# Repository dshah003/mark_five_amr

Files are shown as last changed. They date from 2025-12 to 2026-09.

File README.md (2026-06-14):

# Mark Five AMR

Jetson Nano based mobile robot with SLAM and autonomous navigation capability, powered by **ROS2 Jazzy + Nav2**.

## Overview

Mark Five AMR is a differential-drive robot platform designed for autonomous navigation and manipulation tasks. The robot uses:
- **Jetson Nano** as the main computer
- **Arduino Mega** for motor control and encoder reading
- **2x BTS7960 (IBT-2)** motor driver modules (one per motor)
- **Intel RealSense D435** depth camera for perception
- **ICM-20948 9-DOF IMU** for sensor fusion (gyro-assisted odometry)
- **Lite Arm i2** 3-DOF robotic arm with PCA9685 PWM driver

## Quick Start

### Prerequisites

#### Install Docker
Follow instructions at https://docs.docker.com/engine/install/ubuntu/

#### Post Installation
```bash
sudo groupadd docker
sudo usermod -aG docker $USER
newgrp docker  # Or logout and log back in
```

### External Dependencies (Build from Source)

The following packages must be cloned into `src/` before building:

```bash
cd ~/mark_five_amr/src

# ICM-20948 IMU driver (requires: pip3 install sparkfun-qwiic-icm20948)
# Note: after cloning, icm20948_node.py must be patched to remove the
# imu.connected check, which fails on Jetson Nano's I2C implementation.
# See the IMU Troubleshooting section below.
git clone https://github.com/norlab-ulaval/ros2_icm20948.git
```

### Docker Setup

```bash
# Build Docker image
cd docker && ./build.sh

# Start container
./start.sh

# Access shell
./bash.sh
```

### Build and Run

```bash
# Inside Docker container
cd ~/mark_five_amr
colcon build
source install/setup.bash

# Launch full robot bringup
ros2 launch mark_five_bot bringup.launch.py

# Or with camera
ros2 launch mark_five_bot bringup.launch.py use_camera:=true
```

## Arduino Setup

The Arduino uses a lightweight serial protocol. A Python ROS2 node (`serial_bridge.py`) handles the translation between serial and ROS2 topics.

### Upload Firmware
```bash
# For BTS7960 motor drivers (current hardware, no library needed)
arduino_ws/Robot_Node_BTS7960/Robot_Node_BTS7960.ino

# For L293DNE H-Bridge (legacy)
arduino_ws/Robot_Node/Robot_Node.ino
```

## Launch Files

### Standalone Mode (single machine)

| Launch File | Description |
|---|---|
| `bringup.launch.py` | Full robot bringup (serial + odometry + IMU/EKF + optional nav) |

### Distributed Mode (Jetson + Workstation)

| Launch File | Description |
|---|---|
| `robot.launch.py` | Jetson-side nodes (serial, odometry, IMU, EKF, camera) |
| `workstation.launch.py` | Workstation-side nodes (SLAM/Nav2, RViz, optional teleop) |

### Component Launch Files

| Launch File | Description |
|---|---|
| `serial.launch.py` | Serial bridge to Arduino |
| `odometry.launch.py` | Encoder-based odometry node |
| `imu.launch.py` | ICM-20948 IMU driver |
| `ekf.launch.py` | EKF sensor fusion (odometry + IMU) |
| `camera.launch.py` | RealSense D435 camera |
| `teleop_keyboard.launch.py` | Keyboard teleoperation |
| `teleop_joy.launch.py` | Joystick teleoperation |
| `navigation.launch.py` | Nav2 navigation stack (SLAM or localization) |
| `slam.launch.py` | Laser SLAM with slam_toolbox |
| `rtabmap_slam.launch.py` | Visual SLAM with RTAB-Map |
| `localization.launch.py` | Localization with pre-built map (AMCL) |
| `mission_manager.launch.py` | Waypoint mission manager |

### Arm Launch Files

| Launch File | Description |
|---|---|
| `arm.launch.py` | Arm controller only (programmatic use) |
| `arm_test.launch.py` | Arm controller + GUI sliders + RViz |
| `display.launch.py` | URDF visualization only (no hardware) |

### Examples

```bash
# Full robot bringup
ros2 launch mark_five_bot bringup.launch.py

# With camera
ros2 launch mark_five_bot bringup.launch.py use_camera:=true

# SLAM mode (build maps)
ros2 launch mark_five_bot bringup.launch.py use_camera:=true use_nav:=true nav_mode:=slam

# Navigation mode (use saved map)
ros2 launch mark_five_bot bringup.launch.py use_camera:=true use_nav:=true nav_mode:=localization map:=/path/to/map.yaml

# Distributed mode - on Jetson
ros2 launch mark_five_bot robot.launch.py
ros2 launch mark_five_bot robot.launch.py camera_mode:=visual_slam

# Distributed mode - on Workstation
ros2 launch mark_five_bot workstation.launch.py slam_mode:=visual teleop:=keyboard
```

## Navigation

### SLAM Mode (Building Maps)
```bash
# Launch robot with SLAM
ros2 launch mark_five_bot bringup.launch.py use_camera:=true use_nav:=true nav_mode:=slam

# Drive around to build the map, then save it
ros2 run nav2_map_server map_saver_cli -f ~/mark_five_amr/src/mark_five_bot/maps/my_map
```

### Localization Mode (Using Saved Maps)
```bash
# Launch with pre-built map
ros2 launch mark_five_bot bringup.launch.py use_camera:=true use_nav:=true nav_mode:=localization map:=/full/path/to/map.yaml

# Open RViz with navigation config
rviz2 -d ~/mark_five_amr/src/mark_five_description/rviz/navigation.rviz

# Set initial pose (2D Pose Estimate tool in RViz)
# Set goal (2D Goal Pose tool in RViz)
```

### Navigation Parameters
Key parameters in `src/mark_five_bot/config/nav2_params.yaml`:
- **Robot radius:** 0.12m
- **Max velocity:** 0.20 m/s linear, 1.0 rad/s angular
- **Controller:** Regulated Pure Pursuit
- **Planner:** NavFn

### Waypoint Mission Manager
```bash
# Launch navigation with mission manager
ros2 launch mark_five_bot navigation.launch.py mode:=localization use_mission_manager:=true

# Load waypoints
ros2 topic pub --once /mission/waypoints geometry_msgs/PoseArray \
  "{header: {frame_id: 'map'}, poses: [\
    {position: {x: 1.0, y: 0.0, z: 0.0}, orientation: {w: 1.0}},\
    {position: {x: 1.0, y: 1.0, z: 0.0}, orientation: {w: 1.0}}\
  ]}"

# Start mission
ros2 service call /mission/start std_srvs/srv/Trigger
```

## IMU and Sensor Fusion

The ICM-20948 9-DOF IMU is fused with wheel odometry using an EKF (`robot_localization` package). Only gyroscope data is used (accelerometer disabled due to vibration noise), providing ~40% reduction in yaw drift during turns.

**Hardware connection (Jetson Nano I2C):**
```
ICM-20948 VIN → Pin 1  (3.3V)
ICM-20948 GND → Pin 6  (GND)
ICM-20948 SDA → Pin 3  (I2C Bus 1 SDA)
ICM-20948 SCL → Pin 5  (I2C Bus 1 SCL)
```

**Verify I2C connection:**
```bash
sudo i2cdetect -y -r 1  # Should show 0x68
```

**Disable IMU if not connected:**
```bash
ros2 launch mark_five_bot robot.launch.py imu:=false
```

### IMU Troubleshooting

**`isDeviceConnected` returns False on Jetson Nano:**
The SparkFun qwiic library's `isDeviceConnected()` uses an I2C probe method that doesn't work on Jetson Nano, even when the device is present and fully functional. The node crashes on `begin()` as a result.

Fix — remove the `connected` check in `src/src/ros2_icm20948/ros2_icm20948/icm20948_node.py`:
```python
# Remove these lines:
if not self.imu.connected:
    self.logger.info("The Qwiic ICM20948 device isn't connected...")

# Keep:
self.imu.begin()
```

Then rebuild:
```bash
colcon build --packages-select ros2_icm20948
```

## Robotic Arm (Lite Arm i2)

3-DOF parallel linkage arm (Thingiverse 480446) with 3x Power HD 1501 MG servos, controlled via PCA9685 PWM driver.

**Hardware connection (shares I2C bus with IMU):**
```
PCA9685 VCC → Pin 1  (3.3V)
PCA9685 GND → Pin 6  (GND)
PCA9685 SDA → Pin 3  (I2C Bus 1 SDA)
PCA9685 SCL → Pin 5  (I2C Bus 1 SCL)
PCA9685 V+  → External 5-6V supply (required for servo power)
```

**Quick start:**
```bash
# On Jetson: run arm controller
ros2 launch mark_five_arm arm_test.launch.py use_rviz:=false use_gui:=false

# Move arm
ros2 topic pub --once /arm/joint_commands sensor_msgs/JointState \
  "{name: ['base', 'shoulder', 'elbow'], position: [0.0, 0.5, -0.3]}"

# Home / relax
ros2 service call /arm/home std_srvs/srv/Trigger
ros2 service call /arm/relax std_srvs/srv/Trigger
```

## Configuration

All parameters are stored in YAML config files:

```
src/mark_five_bot/config/
├── robot_params.yaml          # Physical robot parameters
├── odometry.yaml              # Odometry node settings
├── robot_localization.yaml    # EKF sensor fusion (odometry + IMU)
├── camera.yaml                # RealSense camera settings
├── teleop.yaml                # Teleop (joystick/keyboard) settings
├── nav2_params.yaml           # Nav2 navigation parameters
├── slam_toolbox_params.yaml   # Laser SLAM parameters
├── rtabmap_params.yaml        # Visual SLAM parameters
└── mission_manager.yaml       # Waypoint mission manager settings

src/mark_five_arm/config/
└── arm_params.yaml            # Servo PWM calibration and joint limits
```

## Teleoperation

### Keyboard Control
```bash
# Must run directly (not via launch file)
ros2 run teleop_twist_keyboard teleop_twist_keyboard
```

### Joystick Control
```bash
ros2 launch mark_five_bot teleop_joy.launch.py
```
Hold the enable button (Button 2) while moving the left joystick.

### Manual cmd_vel Publishing
```bash
ros2 topic pub /cmd_vel geometry_msgs/msg/Twist "{linear: {x: 0.3}, angular: {z: 0.0}}" --once
```

## Odometry

The odometry node computes robot position from encoder ticks using differential drive kinematics. When the IMU is connected, the EKF fuses odometry with gyroscope data for improved yaw accuracy.

### Verify Odometry
```bash
ros2 topic echo /odom                              # Raw wheel odometry
ros2 topic echo /odometry/filtered                 # EKF-fused odometry
ros2 run tf2_ros tf2_echo odom base_footprint
ros2 run tf2_tools view_frames
```

## URDF Visualization

```bash
ros2 launch mark_five_description display.launch.py
```

## Robot Specifications

| Parameter | Value |
|---|---|
| Wheel Diameter | 0.055 m |
| Wheel Base | 0.14 m |
| Encoder Ticks per Revolution | 540 |
| Ticks per Meter | 3125 |
| Max Velocity | ~0.37 m/s |

## Project Structure

```
mark_five_amr/
├── src/
│   ├── mark_five_bot/           # Main robot package
│   │   ├── config/              # YAML configuration files
│   │   ├── launch/              # Python launch files
│   │   ├── maps/                # Saved map files
│   │   ├── mark_five_bot/       # Python nodes (serial_bridge, mission_manager)
│   │   └── src/                 # C++ nodes (odometry_node)
│   ├── mark_five_description/   # Robot URDF and RViz configs
│   ├── mark_five_arm/           # Robotic arm package (Lite Arm i2)
│   └── ros2_icm20948/           # IMU driver (cloned from norlab-ulaval)
├── arduino_ws/                  # Arduino firmware
├── docker/                      # Docker configuration
└── docs/                        # Documentation
```

## Documentation

- [Project Roadmap](docs/01-Roadmap.md)
- [System Architecture](docs/02-Architecture.md)
- [Package Reference](docs/05-Package-Reference.md)

## References

- ROS2 Jazzy: https://docs.ros.org/en/jazzy/
- Nav2 Navigation: https://nav2.org/
- slam_toolbox: https://github.com/SteveMacenski/slam_toolbox
- ros2_icm20948: https://github.com/norlab-ulaval/ros2_icm20948
- Lite Arm i2: https://www.thingiverse.com/thing:480446

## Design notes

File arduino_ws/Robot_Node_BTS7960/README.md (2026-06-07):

# Robot_Node_BTS7960

Arduino firmware for Mark Five AMR using **2x BTS7960 (IBT-2)** H-bridge motor driver modules.

**Communication:** Simple serial protocol with ROS2 Python bridge (no library installation needed)

## Why BTS7960?

| Specification | BTS7960 (IBT-2) | Sabertooth 2x12 | L293DNE |
|---|---|---|---|
| Voltage Drop  | <0.5V (MOSFET)  | <0.5V (MOSFET)  | ~3-4V (Darlington) |
| Current (cont)| 43A per channel | 12A per channel | 0.6A per channel |
| Current (peak)| 43A per channel | 25A per channel | 1.2A per channel |
| Control | PWM (0-255) | Serial library  | PWM |
| Modules needed| 2 (one per motor)| 1 | 1 |
| Library | None (built-in) | Dimension Eng.  | None |

## Requirements

### Hardware
- Arduino Mega 2560
- 2x BTS7960 / IBT-2 motor driver modules
- 2x Hall encoder DC geared motors (12V)
- 12V power supply (5A+ recommended)

### Software
- No external library needed — uses standard Arduino `analogWrite()`

## Serial Protocol

```
Arduino TX (publishes):  "t,<left_ticks>,<right_ticks>\n"
Arduino RX (receives):   "v,<linear_x>,<angular_z>\n"
```

The ROS2 `serial_bridge.py` node translates this to ROS2 topics.

## Wiring

### BTS7960 to Arduino Mega

Each BTS7960 module has 6 control pins (RPWM, LPWM, R_EN, L_EN, VCC, GND):

```
+-------------+         +-------------------+         +-------------------+
| Arduino     |         | Left BTS7960      |         | Right BTS7960     |
| Mega 2560   |         |                   |         |                   |
|             |         |  RPWM  (forward)  |         |  RPWM  (forward)  |
|  Pin 5 -----+-------->|  RPWM             |         |                   |
|  Pin 4 -----+-------->|  LPWM             |         |                   |
|  Pin 6 -----+-------->|  R_EN             |         |                   |
|  Pin 7 -----+-------->|  L_EN             |         |                   |
|             |         |                   |         |                   |
|  Pin 8 -----+---------+-------------------+-------->|  RPWM             |
|  Pin 9 -----+---------+-------------------+-------->|  LPWM             |
|  Pin 10 ----+---------+-------------------+-------->|  R_EN             |
|  Pin 11 ----+---------+-------------------+-------->|  L_EN             |
|             |         |                   |         |                   |
|  5V --------+-------->|  VCC              |-------->|  VCC              |
|  GND -------+-------->|  GND              |-------->|  GND (logic)      |
+-------------+         |                   |         |                   |
                        |  B+   B-          |         |  B+   B-          |
  12V Supply ---------->|  B+               |-------->|  B+               |
  GND ----------------->|  B-               |-------->|  B-               |
                        |                   |         |                   |
                        |  M+ (OUT1)        |         |  M+ (OUT1)        |
  Left Motor  <---------|  M+ / M-          | Right   |  M+ / M-  ------->| Right Motor
                        +-------------------+         +-------------------+
```

**Important:** The B+/B- power terminals carry motor current (up to 43A peak). Use adequately rated wire (16AWG minimum).

### Pin Summary

| Arduino Pin | BTS7960 Module | Signal | Description |
|---|---|---|---|
| 5  | Left  | RPWM | Left motor forward PWM |
| 4  | Left  | LPWM | Left motor reverse PWM |
| 6  | Left  | R_EN | Left module enable (right half-bridge) |
| 7  | Left  | L_EN | Left module enable (left half-bridge) |
| 8  | Right | RPWM | Right motor forward PWM |
| 9  | Right | LPWM | Right motor reverse PWM |
| 10 | Right | R_EN | Right module enable (right half-bridge) |
| 11 | Right | L_EN | Right module enable (left half-bridge) |
| 21 (INT0) | — | Left Encoder A  | Interrupt — tick counting |
| 20 | — | Left Encoder B  | Direction sensing |
| 3  (INT1) | — | Right Encoder A | Interrupt — tick counting |
| 2 | — | Right Encoder B | Direction sensing |

## Installation

1. **Open `Robot_Node_BTS7960.ino`** in Arduino IDE — no library installation needed

2. **Wire connections** per the diagram above

3. **Upload firmware** to Arduino Mega:
   - Board: Arduino Mega 2560
   - Port: /dev/ttyACM0

4. **Launch ROS2 robot**:
   ```bash
   ros2 launch mark_five_bot bringup.launch.py
   ```

5. **Test with ROS2**:
   ```bash
   ros2 topic echo /left_ticks
   ros2 topic echo /right_ticks
   ros2 run teleop_twist_keyboard teleop_twist_keyboard
   ```

## Tuning

Initial constants are scaled from the previous Sabertooth values and will need tuning:

| Constant | Value | Description |
|---|---|---|
| `K_P` | 278 | PWM per (m/s) — tune first |
| `b` | 52 | Static PWM offset (deadband compensation) |
| `PWM_MIN` | 60 | Below this → 0 (deadband) |
| `PWM_MAX` | 100 | Safety cap during initial testing (0–255) |
| `PWM_TURN` | 80 | Fixed PWM for turn commands |
| `DRIFT_MULTIPLIER` | 120 | Straight-line correction gain |

**Tuning procedure:**
1. Set `PWM_MAX = 60` and send a `linear_x = 0.1` command — robot should move slowly
2. If it doesn't move, increase `b` or lower `PWM_MIN`
3. Gradually increase `PWM_MAX` to the desired top speed
4. Adjust `DRIFT_MULTIPLIER` if the robot curves during straight-line motion

## Troubleshooting

### Motors don't move
1. Check EN pins: `R_EN` and `L_EN` must be HIGH (set in `setup()`)
2. Check B+/B- have 12V connected to both modules
3. Verify 5V/GND logic connections to VCC/GND on each module
4. Check serial_bridge is running: `ros2 node list | grep serial_bridge`

### Motors spin wrong direction
Swap the motor wire connections (M+ and M−) on the module, **or** swap the RPWM/LPWM pin numbers for that motor in the `#define` block at the top of the sketch.

### Robot drifts to one side
Adjust `DRIFT_MULTIPLIER` (increase to correct more, decrease if oscillating).

### No encoder ticks
- Verify encoder wires on pins 21/20 (left) and 3/2 (right)
- Check encoder power supply (typically 5V from Arduino)

## Robot Parameters

| Parameter | Value | Description |
|---|---|---|
| WHEEL_RADIUS | 0.035 m | Wheel radius (70mm diameter) |
| WHEEL_BASE | 0.36 m | Distance between wheels |
| TICKS_PER_REVOLUTION | 540 | Encoder ticks per revolution |
| TICKS_PER_METER | 2456 | Encoder ticks per meter |

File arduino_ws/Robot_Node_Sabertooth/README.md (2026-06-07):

#include <Sabertooth.h>

# Robot_Node_Sabertooth

Arduino firmware for Mark Five AMR using **Sabertooth 2x12 v1.00** motor driver.

This is an alternative to the original `Robot_Node.ino` which uses the L293DNE H-Bridge.

**Communication:** Simple serial protocol with ROS2 Python bridge (no ros2arduino/micro-ROS needed)

## Why Sabertooth 2x12?

| Specification | Sabertooth 2x12 | L293DNE |
|---|---|---|
| Voltage Drop  | <0.5V (MOSFET)  | ~3-4V (Darlington) |
| Current (cont)| 12A per channel | 0.6A per channel |
| Current (peak)| 25A per channel | 1.2A per channel |
| Protection | Thermal, overcurrent, undervoltage | Thermal only |

## Requirements

### Hardware
- Arduino Mega 2560
- Sabertooth 2x12 motor driver (tested with v1.00)
- 2x Hall encoder DC geared motors (25GA370 or similar, 12V)
- 12V power supply (3A+ recommended)

### Software
- **Sabertooth Arduino Library** by Dimension Engineering
  - Install via: Sketch -> Include Library -> Manage Libraries -> Search "Sabertooth"
  - Or download from: https://www.dimensionengineering.com/info/arduino

**Note:** ros2arduino and micro-ROS are NOT needed. The simple serial protocol is more reliable on Arduino Mega's limited 8KB RAM.

## Serial Protocol

The Arduino uses a lightweight text-based serial protocol:

```
Arduino TX (publishes):  "t,<left_ticks>,<right_ticks>\n"
Arduino RX (receives):   "v,<linear_x>,<angular_z>\n"
```

The ROS2 `serial_bridge.py` node translates this to ROS2 topics.

## DIP Switch Configuration

**Packetized Serial Mode, Address 128:**

```
Switch: 1   2   3   4   5   6
        OFF OFF ON  ON  ON  ON
```

Use the DIP Wizard for other configurations:
http://www.dimensionengineering.com/datasheets/SabertoothDIPWizard/start.htm

## Wiring Diagram

```
+-------------+                     +-----------------+
| Arduino     |                     |  Sabertooth 2x12|
| Mega 2560   |                     |                 |
|             |                     |  S1    S2       |
|  Pin 18 TX1 +-------------------->|  S1             |
|             |                     |                 |
|         GND +-------------------->|  0V             |
+-------------+                     |                 |
                                    |  B+    B-       |
      +12V DC Supply +------------->|  B+             |
      (3A+ recommended)             |                 |
                   GND +----------->|  B-             |
                                    |                 |
                                    |  M1A  M1B       |
      Left Motor <------------------|  M1A  M1B       |
                                    |                 |
                                    |  M2A  M2B       |
      Right Motor <-----------------|  M2A  M2B       |
                                    +-----------------+
```

## Pin Connections

### Arduino Mega to Sabertooth

| Arduino Pin | Sabertooth | Description |
|---|---|---|
| Pin 18 (TX1)| S1 | Serial TX (commands) |
| GND | 0V | Common ground |

### Arduino Mega to Encoders

| Arduino Pin | Encoder | Description |
|---|---|---|
| Pin 21 (INT0) | Left Encoder A  | Interrupt - tick counting |
| Pin 20 | Left Encoder B  | Direction sensing |
| Pin 3 (INT1)  | Right Encoder A | Interrupt - tick counting |
| Pin 2 | Right Encoder B | Direction sensing |

### Motor Connections

| Sabertooth | Motor |
|---|---|
| M1A, M1B | Left Motor terminals |
| M2A, M2B | Right Motor terminals |

**Note:** If motors spin in wrong direction, swap M1A/M1B or M2A/M2B, or swap motor(1)/motor(2) in code.

## ROS2 Topics (via serial_bridge.py)

### Published Topics

| Topic | Type | Description |
|---|---|---|
| `/left_ticks` | std_msgs/Int16 | Left wheel encoder ticks |
| `/right_ticks` | std_msgs/Int16 | Right wheel encoder ticks |

### Subscribed Topics

| Topic | Type | Description |
|---|---|---|
| `/cmd_vel` | geometry_msgs/Twist | Velocity commands |

## Installation

1. **Install Sabertooth library** in Arduino IDE:
   - Sketch -> Include Library -> Manage Libraries
   - Search "Sabertooth" -> Install

2. **Set DIP switches**: `OFF OFF ON ON ON ON`

3. **Wire connections** per the diagram above

4. **Upload firmware** to Arduino Mega:
   - Board: Arduino Mega 2560
   - Port: /dev/ttyACM0

5. **Launch ROS2 robot**:
   ```bash
   ros2 launch mark_five_bot bringup.launch.py
   ```
   This automatically starts the serial_bridge node.

6. **Test with ROS2**:
   ```bash
   # Terminal 1 - Launch robot (already running)

   # Terminal 2 - Monitor encoder ticks
   ros2 topic echo /left_ticks
   ros2 topic echo /right_ticks

   # Terminal 3 - Keyboard teleop
   ros2 run teleop_twist_keyboard teleop_twist_keyboard
   ```

## Troubleshooting

### Motors don't move

1. Check DIP switch settings: `OFF OFF ON ON ON ON`
2. Verify power supply connected to B+/B-
3. Check S1 connected to Arduino Pin 18
4. Ensure common ground between Arduino and Sabertooth
5. Verify Sabertooth library is installed
6. Check serial_bridge node is running: `ros2 node list`

### No topics appearing

1. Check serial_bridge is running:
   ```bash
   ros2 node list | grep serial_bridge
   ```
2. Check Arduino is connected to correct port (`/dev/ttyACM0`)
3. Verify baud rate matches (115200)
4. Test serial directly:
   ```bash
   cat /dev/ttyACM0
   # Should see: t,0,0 (tick messages)
   ```

### Motors spin wrong direction

Swap motor wire connections (M1A/M1B or M2A/M2B), or in the code swap:
```cpp
ST.motor(1, leftWithSign);   // Try swapping 1 and 2
ST.motor(2, rightWithSign);
```

### Robot drifts to one side

Adjust the `DRIFT_MULTIPLIER` constant in the code (default: 120).

## Robot Parameters

| Parameter | Value | Description |
|---|---|---|
| WHEEL_RADIUS | 0.055 m | Wheel radius |
| WHEEL_BASE | 0.14 m | Distance between wheels |
| TICKS_PER_REVOLUTION | 540 | Encoder ticks per wheel revolution |
| TICKS_PER_METER | 3125 | Encoder ticks per meter traveled |

## Power Supply Requirements

| Specification | Recommended |
|---|---|
| Voltage | 12-14V DC |
| Current | 3A minimum, 5A preferred |
| Type | Regulated DC supply or 3S LiPo battery |

**Important:** Do not use a 5V->12V boost converter. The Sabertooth requires direct 12V with adequate current capacity.

## Files

- `Robot_Node_Sabertooth.ino` - Main Arduino firmware
- `README.md` - This file

## Test Code

For standalone motor testing (without ROS2), see:
- `arduino_ws/test_sabertooth/test_sabertooth.ino` - Full test sequence
- `arduino_ws/test_sabertooth_minimal/test_sabertooth_minimal.ino` - Minimal test

## Migration from ROS1

The ROS2 version uses a **simple serial protocol** instead of rosserial. Key changes:
- No ROS libraries needed on Arduino (just Sabertooth library)
- ROS2 `serial_bridge.py` node handles translation
- Much lower memory footprint on Arduino
- More reliable than ros2arduino/micro-ROS on Arduino Mega

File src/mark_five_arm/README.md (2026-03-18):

 # Mark Five Arm - ROS2 Robotic Arm Controller

ROS2 package for controlling a hobby servo-based robotic arm using the PCA9685 PWM driver board.

## Overview

This package provides a ROS2 node that interfaces with a PCA9685 16-channel PWM driver to control hobby servos for a robotic arm. It converts joint position commands (in radians) to PWM signals and provides services for homing and relaxing the arm.

### Features

- **ROS2 Jazzy** compatible
- **PCA9685 I2C interface** for controlling up to 16 servos
- **Configurable joint parameters** via YAML files (angle ranges, PWM limits, home positions)
- **ROS2 services** for homing and relaxing the arm
- **Joint state publishing** for monitoring current positions
- **Simulation mode** for testing without hardware
- **GUI testing tool** with joint sliders for manual control

## Supported Arm Designs

This package is configured for the **Lite Arm i2** (Thingiverse thing:480446) - a 4-DOF robotic arm modeled after the uFactory uArm.

**Lite Arm i2 Specifications (Official):**
- **3-4 servos:** 3x Power HD 1501 MG (base, shoulder, elbow) + optional gripper servo
- **4 DOF:** Base rotation (Z-axis), Shoulder (Y-axis), Elbow (Y-axis), Gripper
- **Design:** Inspired by ABB IRB-660 industrial robot
- **3D Printed:** All structural parts are 3D printable
- **STL Files:** Available on [Thingiverse thing:480446](https://www.thingiverse.com/thing:480446)
- **Dimensions (from STL analysis):**
  - Upper arm: 230mm (20_21B.stl)
  - Forearm: 180mm (15C.stl)
  - Base bearing: 35mm ID × 47mm OD × 7mm (6807 2RS)
- **PWM Range (calibrated):**
  - Base: 690-2600μs (center: 1645μs)
  - Shoulder: 900-2000μs (center: 1450μs)
  - Elbow: 900-2350μs (center: 1625μs)

The URDF (`urdf/lite_arm_i2.urdf.xacro`) has been updated with dimensions extracted from the official STL files.

**Arm Configuration (3-DOF, parallel linkage):**
```
       End Effector (passive)
            │
            │ (no servo - parallel linkage keeps it level)
            ▼
      ┌─────────────┐
      │  Forearm    │ ← 180mm (15C.stl)
      │ (2 parallel │
      │   links)    │
      └─────┬───────┘
            │ (revolute, Y-axis)
         Elbow (CH2)
            │
      ┌─────────────┐
      │ Upper Arm   │ ← 230mm (20_21B.stl)
      │ (2 parallel │
      │   links)    │
      └─────┬───────┘
            │ (revolute, Y-axis)
       Shoulder (CH1)
            │
      Rotating Base
            │
            │ (revolute, Z-axis)
        Base (CH0)
            │
         ═════════
        Fixed Base
```

**Note:** The parallel linkage mechanism keeps the end effector/tool at a consistent orientation as the arm moves (similar to ABB IRB-660). The URDF simplifies this to a serial chain for basic visualization. For accurate inverse kinematics, the parallel linkage geometry would need to be modeled.

**Optional Gripper:** Add a gripper servo to channel 3 if needed (see `config/arm_params.yaml`).

## Hardware Requirements

### Components

| Component | Specification | Purpose |
|---|---|---|
| **PCA9685** | 16-channel 12-bit PWM driver | Servo control via I2C |
| **Hobby Servos** | 4.8-6V, standard PWM (1000-2000μs) | Arm joints |
| **Power Supply** | 5-6V, ≥2A per servo | Servo power |
| **Jetson Nano** | Or similar SBC with I2C | Robot computer |
| **Jumper Wires** | Female-to-female | I2C connections |

### Official Servos (Lite Arm i2)

As specified in the official parts list:
- **3x Power HD 1501 MG servos** (base, shoulder, forearm) - $15.95 each
  - Operating voltage: 4.8-6V
  - PWM range: Varies per joint (see calibrated values above)
  - Torque: ~15kg-cm @ 6V
- **Optional gripper servo:** Any standard servo (SG90 or similar)

### uArm Swift Pro (Example Configuration)

If using a **uArm Swift Pro** or similar commercial arm:
- Base: 180° rotation
- Shoulder: 0-90° range
- Elbow: 0-90° range
- Wrist: 180° rotation
- Gripper: Open/close (0-60°)

You'll need to replace the original controller with the PCA9685 and rewire the servos.

## Circuit Diagram

### PCA9685 to Jetson Nano I2C Connection

```
┌─────────────────┐              ┌─────────────────────┐
│  Jetson Nano    │              │     PCA9685         │
│  (GPIO Header)  │              │   PWM Driver        │
├─────────────────┤              ├─────────────────────┤
│                 │              │                     │
│  Pin 1 (3.3V) ──┼─────────────▶│ VCC                 │
│  Pin 3 (SDA)  ──┼─────────────▶│ SDA  [CH0]  [CH8]   │
│  Pin 5 (SCL)  ──┼─────────────▶│ SCL  [CH1]  [CH9]   │
│  Pin 6 (GND)  ──┼─────────────▶│ GND  [CH2]  [CH10]  │
│                 │              │      [CH3]  [CH11]  │
│                 │              │      [CH4]  [CH12]  │
│                 │              │      [CH5]  [CH13]  │
│                 │              │      [CH6]  [CH14]  │
│                 │              │      [CH7]  [CH15]  │
│                 │              │                     │
│                 │              │  V+  ───────────┐   │
│                 │              │  GND ─────────┐ │   │
└─────────────────┘              └───────────────┼─┼───┘
                                                 │ │
                                                 │ │
                                   ┌─────────────┘ │
                                   │  ┌────────────┘
                                   ▼  ▼
                               ┌──────────────┐
                               │ Power Supply │
                               │   5-6V DC    │
                               │   ≥2A/servo  │
                               └──────────────┘
```

### Servo Connections

Each servo connects to a PCA9685 channel:

```
Servo Wire Colors (Standard):
  - Red/Orange: Power (V+) ──▶ PCA9685 V+ terminal
  - Brown/Black: Ground (GND) ──▶ PCA9685 GND terminal
  - Yellow/White: Signal (PWM) ──▶ PCA9685 channel pin

Example 6-DOF Arm:
  CH0: Base rotation servo
  CH1: Shoulder servo
  CH2: Elbow servo
  CH3: Wrist pitch servo
  CH4: Wrist roll servo
  CH5: Gripper servo
```

### Important Wiring Notes

1. **DO NOT power servos from Jetson's 5V pin** - insufficient current (≥2A per servo needed)
2. **Use separate 5-6V power supply** for servo power (V+/GND terminals on PCA9685)
3. **Common ground** - Connect Jetson GND, PCA9685 GND, and power supply GND together
4. **I2C address** - Default PCA9685 address is 0x40 (verify with `i2cdetect`)
5. **I2C bus sharing** - PCA9685 shares I2C bus 1 with IMU (if installed)

## Software Setup

### 1. Build the Package

```bash
# Navigate to workspace
cd ~/mark_five_amr

# Rebuild Docker image with PCA9685 dependencies
cd docker
./build.sh

# Start container
./start.sh
./bash.sh

# Inside container, build the workspace
cd ~/mark_five_amr
colcon build --packages-select mark_five_arm
source install/setup.bash
```

### 2. Verify I2C Connection

Before running the node, verify the PCA9685 is detected:

```bash
# On Jetson host (not Docker)
sudo apt install i2c-tools
sudo i2cdetect -y -r 1

# Expected output:
#      0  1  2  3  4  5  6  7  8  9  a  b  c  d  e  f
# 00:          -- -- -- -- -- -- -- -- -- -- -- -- --
# ...
# 40: 40 -- -- -- -- -- -- -- -- -- -- -- -- -- -- --  ← PCA9685
# ...
# 60: -- -- -- -- -- -- -- -- 68 -- -- -- -- -- -- --  ← IMU (if present)
```

If not detected:
- Check wiring (SDA, SCL, VCC, GND)
- Verify PCA9685 power LED is on
- Check I2C address jumpers on PCA9685 board (default 0x40)

### 3. Configure Servo Parameters

Edit `config/arm_params.yaml` to match your arm:

```yaml
# For each joint, configure:
base:
  channel: 0           # PCA9685 channel (0-15)
  min_angle: -1.5708   # Minimum angle in radians
  max_angle: 1.5708    # Maximum angle in radians
  min_pwm: 1000        # PWM value at min_angle (0-4095)
  max_pwm: 2000        # PWM value at max_angle (0-4095)
  home_angle: 0.0      # Home position in radians
  inverted: false      # Reverse direction if true
```

## Measuring and Updating URDF Dimensions

The included URDF has estimated dimensions. For accurate visualization and future kinematics, measure your printed arm and update the URDF.

### What to Measure

Open `urdf/lite_arm_i2.urdf.xacro` and update these properties at the top:

```xml
<!-- Measure these on your printed arm! -->
<xacro:property name="base_height" value="0.050" />      <!-- Base cylinder height -->
<xacro:property name="base_radius" value="0.045" />      <!-- Base cylinder radius -->

<xacro:property name="upper_arm_length" value="0.148" /> <!-- Shoulder to elbow distance -->
<xacro:property name="forearm_length" value="0.160" />   <!-- Elbow to wrist distance -->
<xacro:property name="gripper_length" value="0.080" />   <!-- Gripper reach -->
```

### How to Measure

1. **Base dimensions:**
   - Measure height and radius of the rotating base platform

2. **Upper arm (shoulder to elbow):**
   - Measure center-to-center distance between shoulder servo axis and elbow servo axis
   - This is the most critical dimension for kinematics

3. **Forearm (elbow to wrist/gripper):**
   - Measure center-to-center distance from elbow servo axis to gripper attachment point

4. **Gripper:**
   - Measure from gripper base to tip of fingers when closed

### Verify URDF in RViz

After updating dimensions:

```bash
ros2 launch mark_five_arm display.launch.py
```

Use the joint sliders to move the arm and verify:
- Links are the correct length
- Joints rotate around correct axes
- No unexpected offsets or rotations

## Hardware Assembly

### Parts List

The official Lite Arm i2 parts list is included in `stl/LAi2Partslist.pdf`. Key components:

**Electronics:**
- 3x Power HD 1501 MG servos ($15.95 each)
- 3x 25T servo horns (3mm threaded)
- PCA9685 PWM driver (not in original - added for ROS2 control)

**Mechanical:**
- 24x MF84zz 4x8x3mm flanged ball bearings ($15 for 24)
- 1x 6807 2RS bearing (35mm ID × 47mm OD) for base rotation ($9.47)
- Various 6-32 and 8-32 bolts and nuts (see PDF for full list)

**3D Printed Parts:**
- 30 STL files included in `stl/` directory
- Print all parts in PLA or PETG
- See assembly instructions in `stl/LAi2_Instructions.zip`

### Assembly Notes

1. Follow the official assembly instructions in `LAi2_Instructions.zip`
2. The original design uses direct Arduino control - we're replacing that with PCA9685 for ROS2 integration
3. Wire servos to PCA9685 channels 0-2 (base, shoulder, elbow)
4. Gripper servo (if used) goes to channel 3

## Calibration

### Official PWM Values (Power HD 1501 MG)

The Lite Arm i2 uses **Power HD 1501 MG** servos with these specs (from official Arduino code):

| Position | PWM Value |
|---|---|
| Full left/min | 1000μs |
| **Center** | **1500μs** |
| Full right/max | 2000μs |

These values are **already configured** in `config/arm_params.yaml`. For most builds, no calibration is needed!

### Quick Test (Verify Default Values Work)

```bash
# Terminal 1: Run arm controller
ros2 launch mark_five_arm arm.launch.py

# Terminal 2: Send all servos to center (1500μs)
ros2 topic pub --once /arm/joint_commands sensor_msgs/JointState \
  "{name: ['base', 'shoulder', 'elbow'], position: [0.0, 0.0, 0.0]}"
```

All three servos should move to their center positions. If this works, the default calibration is correct!

### When Calibration IS Needed

Only calibrate if:
1. **Servo moves wrong direction** → Set `inverted: true` for that joint
2. **Center position is off** → Adjust PWM values slightly
3. **Using different servos** → Find their PWM range

### Calibration Process (If Needed)

**Step 1: Check servo direction**
```bash
# Command positive angle for base
ros2 topic pub --once /arm/joint_commands sensor_msgs/JointState \
  "{name: ['base'], position: [0.5]}"
```
- If base rotates counter-clockwise (looking from above): correct
- If base rotates clockwise: set `base.inverted: true` in config

Repeat for shoulder and elbow.

**Step 2: Verify home position**

The arm should be in a safe "home" pose when all joints are at 0.0:
```bash
ros2 service call /arm/home std_srvs/srv/Trigger
```

If the home position causes collisions or looks wrong, adjust `home_angle` for each joint in the config.

**Step 3: Test full range with GUI**
```bash
ros2 launch mark_five_arm arm_test.launch.py
```

Use the sliders to move each joint through its full range. Verify:
- Smooth motion (no jitter)
- No mechanical binding at limits
- Physical arm matches RViz visualization

### Fine-Tuning PWM (Rare)

If servos don't reach full range or overshoot:

```yaml
# In config/arm_params.yaml
base:
  min_pwm: 1000   # Decrease if servo doesn't reach min position
  max_pwm: 2000   # Increase if servo doesn't reach max position
```

The Power HD 1501 MG servos support extended PWM ranges beyond the nominal 1000-2000μs. Calibrated ranges: base (690-2600μs), shoulder (900-2000μs), elbow (900-2350μs).

### Lite Arm i2 Default Calibration

```yaml
# These values should work out-of-the-box for Lite Arm i2
base:
  channel: 0
  min_angle: -1.5708   # -90°
  max_angle: 1.5708    # +90°
  min_pwm: 1000        # Official spec
  max_pwm: 2000        # Official spec
  home_angle: 0.0      # Center
  inverted: false      # Change if needed
```

## Usage

### 1. Visualize URDF Only (No Hardware)

Visualize the arm model in RViz without connecting to hardware:

```bash
ros2 launch mark_five_arm display.launch.py
```

This launches:
- `robot_state_publisher` - publishes URDF transforms
- `joint_state_publisher_gui` - GUI sliders for joint control
- `rviz2` - visualization

Use this to verify your URDF dimensions before connecting servos.

### 2. Test with Hardware (PCA9685 + Servos)

Test actual servo control with GUI and visualization:

```bash
# Full test with RViz
ros2 launch mark_five_arm arm_test.launch.py

# Or without RViz (faster)
ros2 launch mark_five_arm arm_test.launch.py use_rviz:=false
```

This launches:
- `robot_state_publisher` - publishes URDF transforms
- `arm_controller` - controls PCA9685 hardware
- `joint_state_publisher_gui` - GUI sliders send commands to hardware
- `rviz2` - visualization (optional)

Move the sliders and watch both the physical arm and RViz model move together.

### 2b. Distributed Mode (Jetson + Workstation)

When running on a headless Jetson Nano, run the controller on Jetson and GUI/RViz on your workstation:

**On Jetson (headless):**
```bash
ros2 launch mark_five_arm arm_test.launch.py use_rviz:=false use_gui:=false
```

**On Workstation:**
```bash
# RViz only (view arm state)
ros2 launch mark_five_arm display.launch.py use_gui:=false use_rsp:=false

# GUI control (move arm with sliders)
ros2 run joint_state_publisher_gui joint_state_publisher_gui \
  --ros-args -r /joint_states:=/arm/joint_commands
```

Note: `use_rsp:=false` prevents duplicate `robot_state_publisher` since Jetson is already running it.

### 3. Programmatic Control (No GUI)

Control the arm via ROS2 topics:

```bash
# Terminal 1: Start arm controller only
ros2 launch mark_five_arm arm.launch.py

# Terminal 2: Command joints via topic (positions in radians)
ros2 topic pub --once /arm/joint_commands sensor_msgs/JointState \
  "{name: ['base', 'shoulder', 'elbow'], position: [0.5, 0.3, -0.5]}"
```

### Services

```bash
# Move to home position
ros2 service call /arm/home std_srvs/srv/Trigger

# Relax all servos (disable PWM)
ros2 service call /arm/relax std_srvs/srv/Trigger
```

### Monitor Joint States

```bash
# View current joint positions
ros2 topic echo /arm/joint_states

# Check publishing rate
ros2 topic hz /arm/joint_states
```

## ROS2 Interface

### Subscribed Topics

| Topic | Type | Description |
|---|---|---|
| `/arm/joint_commands` | `sensor_msgs/JointState` | Target joint positions (radians) |

### Published Topics

| Topic | Type | Rate | Description |
|---|---|---|---|
| `/arm/joint_states` | `sensor_msgs/JointState` | 10 Hz | Current commanded positions |

### Services

| Service | Type | Description |
|---|---|---|
| `/arm/home` | `std_srvs/Trigger` | Move arm to home position |
| `/arm/relax` | `std_srvs/Trigger` | Disable all servos (zero PWM) |

### Parameters

| Parameter | Type | Default | Description |
|---|---|---|---|
| `i2c_address` | int | 0x40 | PCA9685 I2C address |
| `pwm_frequency` | int | 50 | PWM frequency (Hz) |
| `num_joints` | int | 6 | Number of servo joints |
| `joint_names` | list | ['base', ...] | Joint name list |
| `publish_rate` | float | 10.0 | Joint state publish rate (Hz) |

Per-joint parameters (replace `<joint_name>`):
- `<joint_name>.channel` (int): PCA9685 channel (0-15)
- `<joint_name>.min_angle` (float): Minimum angle (radians)
- `<joint_name>.max_angle` (float): Maximum angle (radians)
- `<joint_name>.min_pwm` (int): PWM at min_angle (0-4095)
- `<joint_name>.max_pwm` (int): PWM at max_angle (0-4095)
- `<joint_name>.home_angle` (float): Home position (radians)
- `<joint_name>.inverted` (bool): Reverse servo direction

## Troubleshooting

### PCA9685 Not Detected

**Problem:** `i2cdetect` doesn't show device at 0x40

**Solutions:**
- Check wiring: VCC, GND, SDA, SCL
- Verify PCA9685 power LED is on
- Try different I2C address (check jumpers on PCA9685 board)
- Test with different I2C bus: `i2cdetect -y -r 0`

### Servo Jitter or Erratic Movement

**Problem:** Servo shakes or moves erratically

**Solutions:**
- Check power supply capacity (≥2A per servo)
- Use thicker power wires to PCA9685 V+ terminal
- Add 100-1000μF capacitor across V+/GND near PCA9685
- Ensure common ground between Jetson, PCA9685, and power supply
- Check for loose connections

### Servo Doesn't Move

**Problem:** No movement when commanding joint

**Solutions:**
- Verify servo is powered (check V+ and GND connections)
- Test PWM with oscilloscope (should see 50Hz signal)
- Check channel number in config matches physical connection
- Try commanding extreme angles: `min_angle` and `max_angle`
- Verify PWM range (1000-2000 is typical, but some servos need 500-2500)

### Wrong Direction

**Problem:** Servo moves opposite to commanded direction

**Solution:**
Set `inverted: true` for that joint in `config/arm_params.yaml`

### Limited Range of Motion

**Problem:** Servo doesn't reach full physical range

**Solutions:**
- Increase PWM range (try `min_pwm: 500`, `max_pwm: 2500`)
- Check servo datasheet for actual PWM range
- Verify no mechanical obstruction

### Node Crashes on Startup

**Problem:** `Adafruit PCA9685 library not found`

**Solution:**
```bash
pip3 install --break-system-packages adafruit-circuitpython-pca9685 Jetson.GPIO
```

**Problem:** `module 'board' has no attribute 'SCL'`

**Solution:** Install Jetson GPIO library:
```bash
pip3 install --break-system-packages Jetson.GPIO
```

**Problem:** `Failed to initialize PCA9685`

**Solutions:**
- Verify I2C connection: `sudo i2cdetect -y -r 1` (should show 0x40)
- Check I2C permissions: Add user to `i2c` group
- Node will fall back to simulation mode if hardware not available

### Direct Hardware Test (No ROS2)

Use the test script for debugging without ROS2:
```bash
python3 src/mark_five_arm/scripts/test_servos.py
```
This allows interactive testing of individual servos with direct PWM control.

## Integration with MoveIt2 (Future)

This package provides low-level servo control. For trajectory planning and inverse kinematics:

1. Create URDF model of your arm
2. Configure MoveIt2 with `moveit_setup_assistant`
3. Create hardware interface that publishes to `/arm/joint_commands`
4. Use MoveIt2 for motion planning and collision avoidance

## Files and Directories

```
mark_five_arm/
├── mark_five_arm/
│   ├── __init__.py
│   └── arm_controller.py        # Main PCA9685 controller node
├── config/
│   └── arm_params.yaml          # Servo configuration (calibrated PWM values)
├── launch/
│   ├── arm.launch.py            # Basic launch (controller only)
│   ├── arm_test.launch.py       # Hardware testing with GUI + RViz
│   └── display.launch.py        # URDF visualization only (no hardware)
├── scripts/
│   └── test_servos.py           # Direct hardware test (no ROS2)
├── rviz/
│   ├── arm.rviz                 # RViz config (legacy)
│   └── display.rviz             # RViz config for URDF display
├── urdf/
│   ├── arm.urdf.xacro           # Generic 6-DOF arm (template)
│   └── lite_arm_i2.urdf.xacro   # Lite Arm i2 specific (4-DOF)
├── CMakeLists.txt
├── package.xml
├── setup.py
├── setup.cfg
└── README.md                    # This file
```

## Contributing

When adding new features:
1. Follow ROS2 best practices
2. Update configuration files
3. Document parameters and topics
4. Test with simulation mode first

## License

MIT License

## References

### Robotic Arm Design
- [Lite Arm i2 on Thingiverse](https://www.thingiverse.com/thing:480446) - Original 3D printable arm design
- [Lite Arm i2 STL Files](https://www.stlfinder.com/3dmodels/open-source-robotic-arm-lite-arm-i2-mod-files/) - Alternative STL sources
- [Lite Arm i1 (Original)](https://www.thingiverse.com/thing:407800) - Earlier version

### Electronics & Software
- [PCA9685 Datasheet](https://cdn-shop.adafruit.com/datasheets/PCA9685.pdf)
- [Adafruit PCA9685 Python Library](https://github.com/adafruit/Adafruit_CircuitPython_PCA9685)
- [ROS2 Jazzy Documentation](https://docs.ros.org/en/jazzy/)
- [MoveIt2 Documentation](https://moveit.picknik.ai/)

### Related Projects
- [Top 10 Open Source Robotic Arms](https://circuitdigest.com/articles/top-10-opensource-robotic-arms-for-beginners) - Comparison of DIY arm designs

## Support

For issues or questions:
- GitHub Issues: [mark_five_amr repository]
- ROS Answers: Tag with `mark-five-arm`

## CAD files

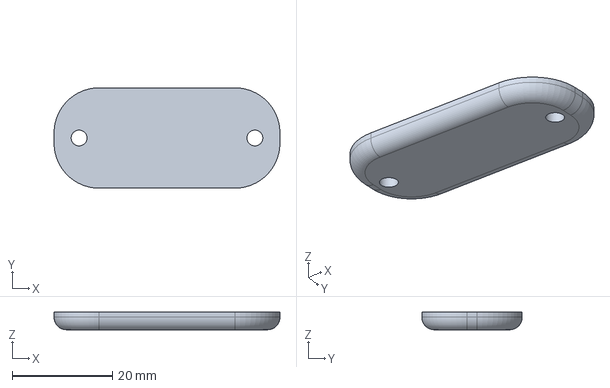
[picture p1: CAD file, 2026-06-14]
cad/back_plate.FCStd
45.0 x 20.0 x 3.50 mm

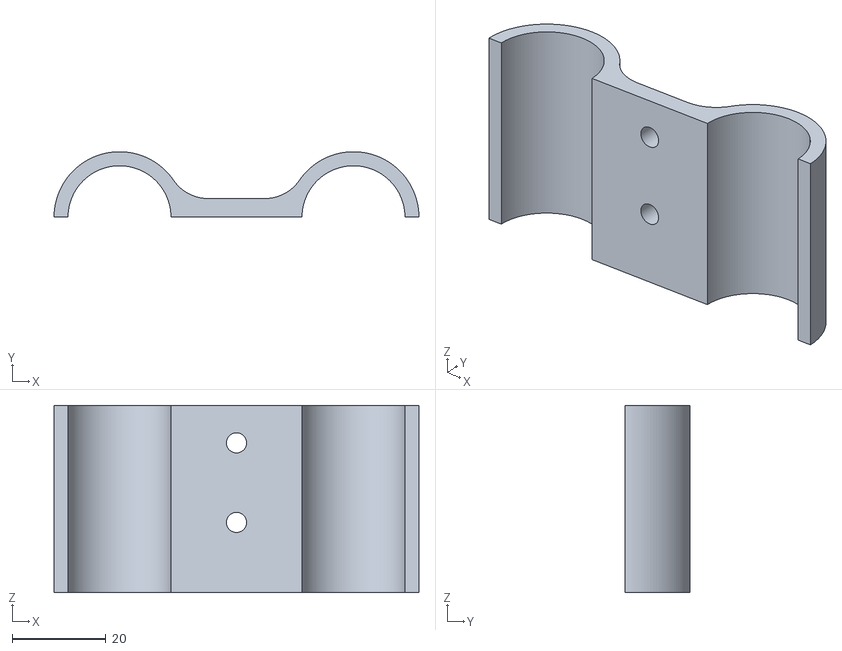
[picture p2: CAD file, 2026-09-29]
cad/Lidar LD19 Clamp/LD19Clamp-Clamp1_v2.stl
78.0 x 14.0 x 40.0

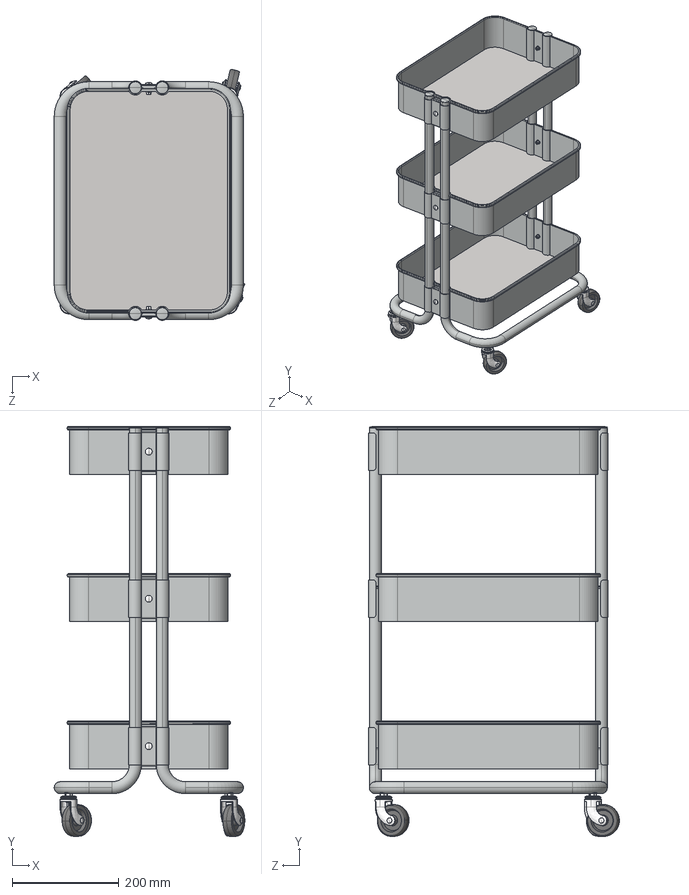
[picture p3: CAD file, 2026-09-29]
cad/raskog-storage-cart-1.snapshot.4/Raskog V1_Render.STEP
356.4 x 766.5 x 468.9 mm
Bottom Stand x 2
Upper Stand x 2
Bottom Frame x 2
Wheel Holder x 4
Bearing Ring x 4
Wheel x 4
Top Bearing Ring x 4
Wheel Pin x 4
Caster Screw x 4
Caster Nut x 4
Box 1_Box 1 x 3
Backet Mount x 6
Backet Screw x 6
Backet Nut x 6

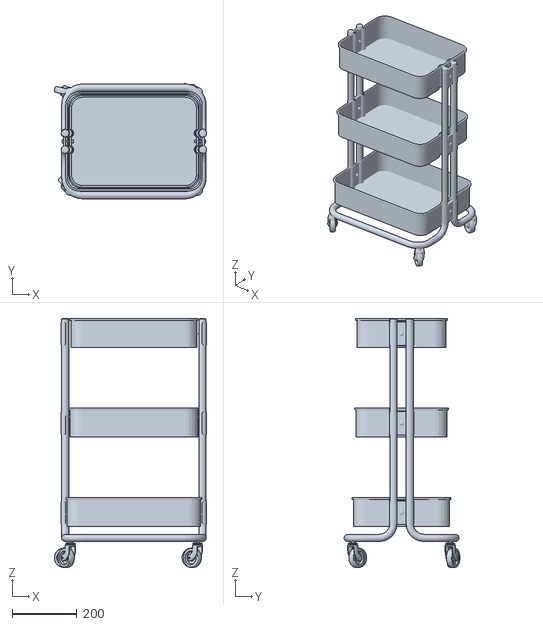
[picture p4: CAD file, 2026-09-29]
src/mark_five_description/meshes/raskog_cart.stl
468.8 x 356.4 x 766.3

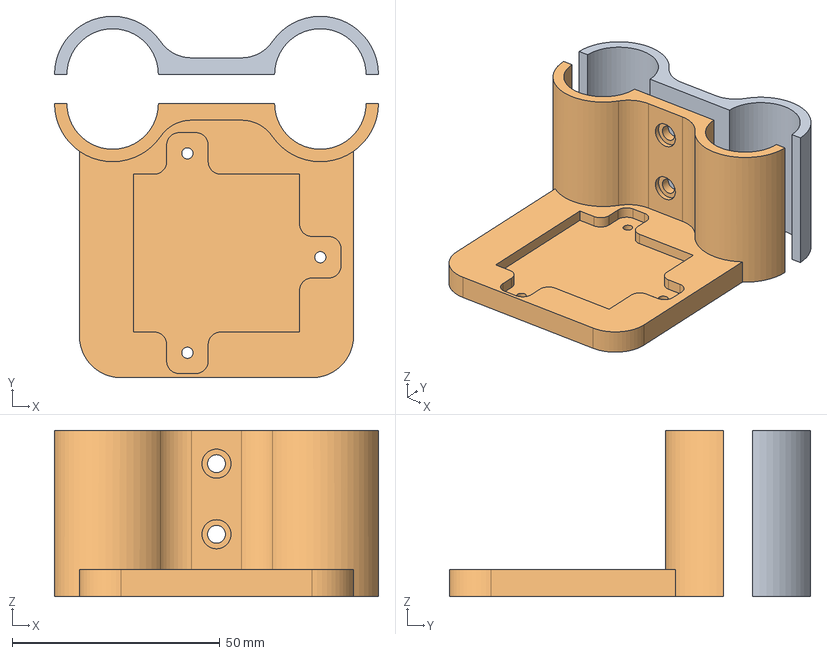
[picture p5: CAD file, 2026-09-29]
cad/Lidar LD19 Clamp/LD19Clamp.FCStd
78.0 x 87.0 x 40.0 mm
Clamp1
Clamp2_LidarHolder

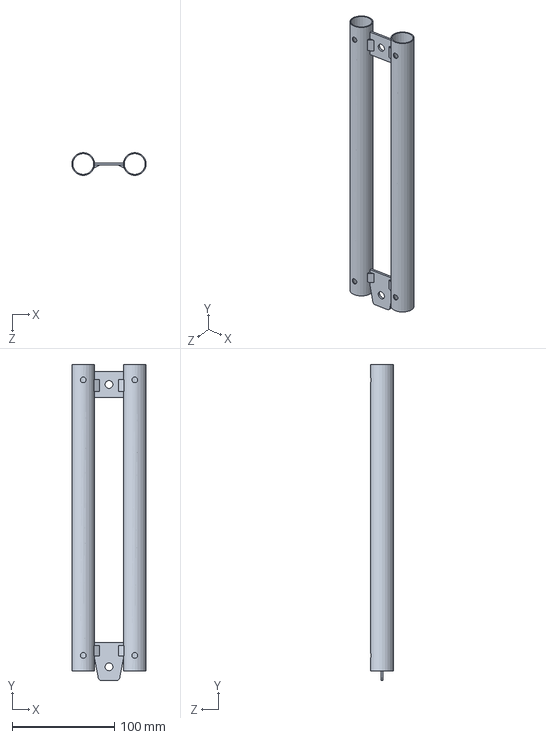
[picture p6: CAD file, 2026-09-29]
cad/raskog-storage-cart-1.snapshot.4/Raskog Assem/Bottom Stand.SLDPRT
72.6 x 308.5 x 22.3 mm

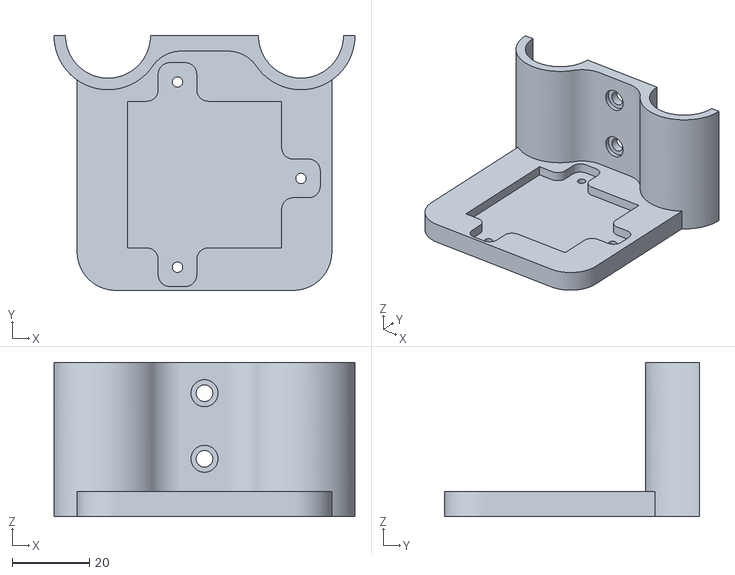
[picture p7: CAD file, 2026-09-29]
cad/Lidar LD19 Clamp/LD19Clamp-Clamp2_LidarHolder_v3.stl
78.0 x 66.0 x 40.0

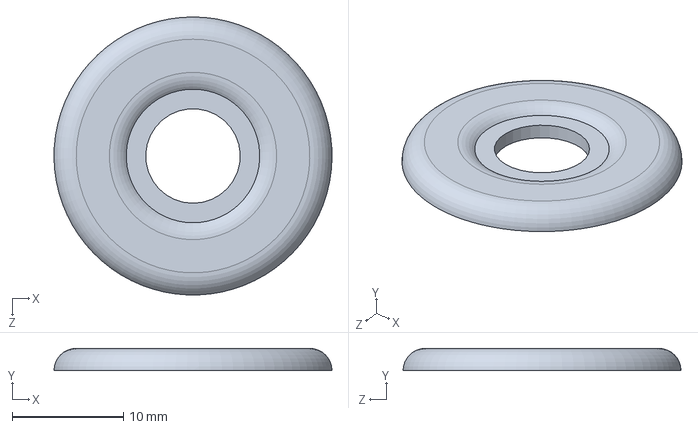
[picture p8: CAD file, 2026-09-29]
cad/raskog-storage-cart-1.snapshot.4/Raskog Assem/Bearing Ring.SLDPRT
25.0 x 2.00 x 25.0 mm

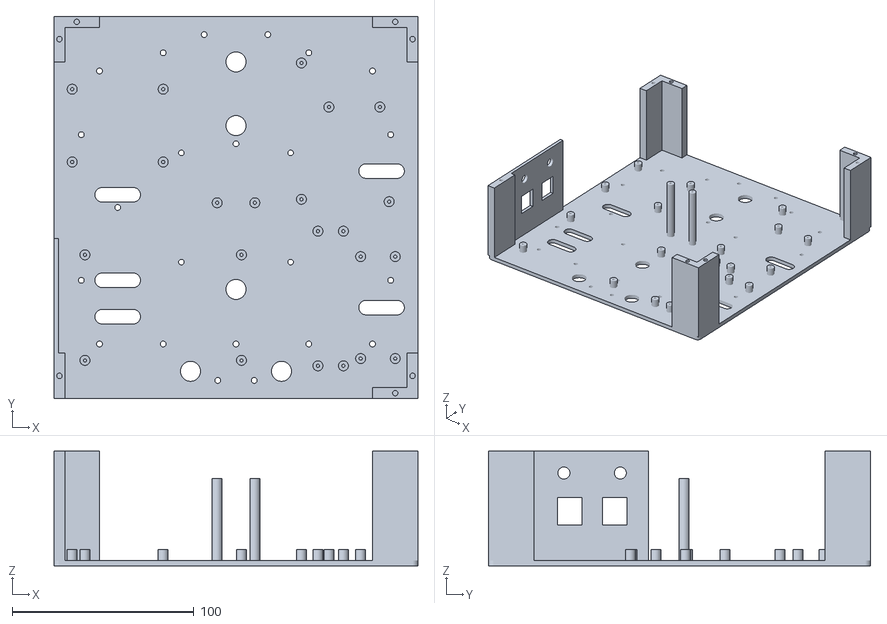
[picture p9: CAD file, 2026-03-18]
cad/robot_chassis_v6.stl
200.0 x 210.0 x 63.0

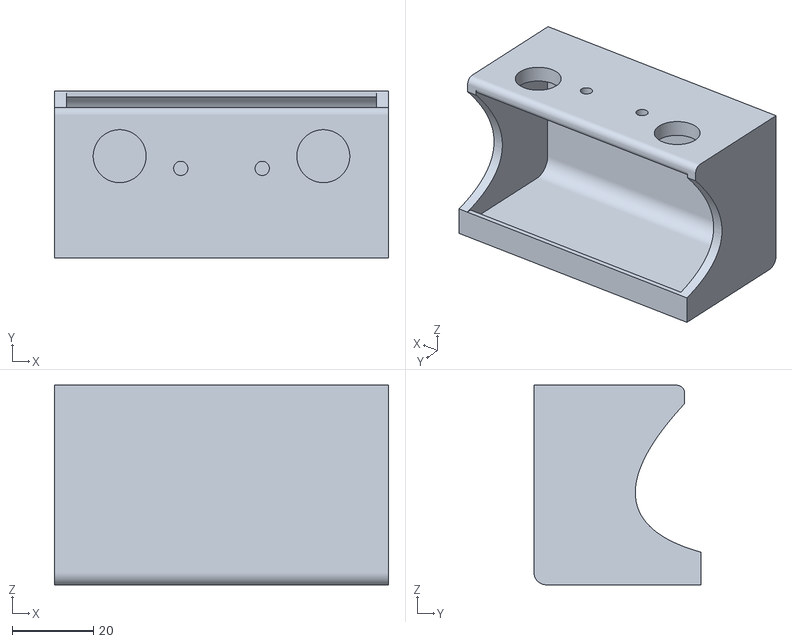
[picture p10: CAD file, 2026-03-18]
cad/battery_holder-Body.stl
82.0 x 41.0 x 49.0

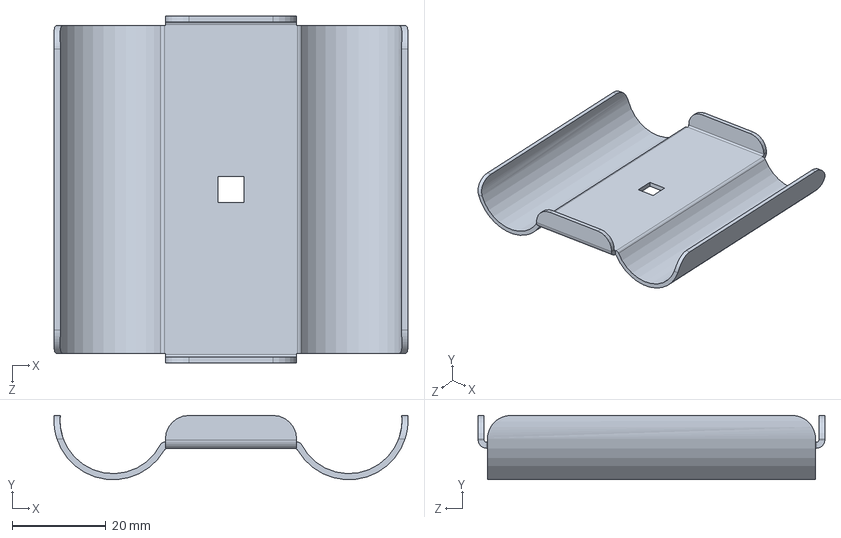
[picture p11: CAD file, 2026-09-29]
cad/raskog-storage-cart-1.snapshot.4/Raskog Assem/Backet Mount.SLDPRT
75.5 x 13.7 x 74.0 mm

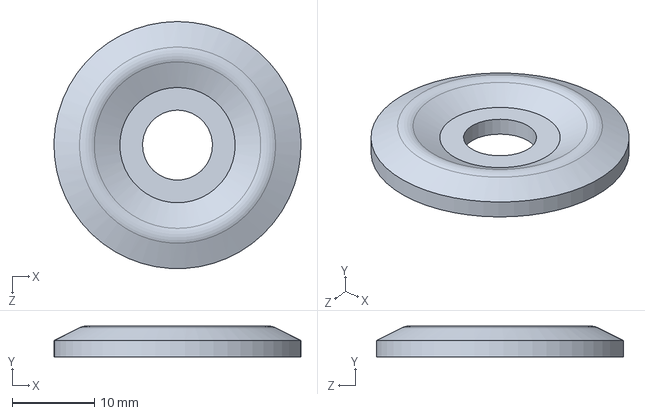
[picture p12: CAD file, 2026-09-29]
cad/raskog-storage-cart-1.snapshot.4/Raskog Assem/Top Bearing Ring.SLDPRT
30.0 x 3.76 x 30.0 mm

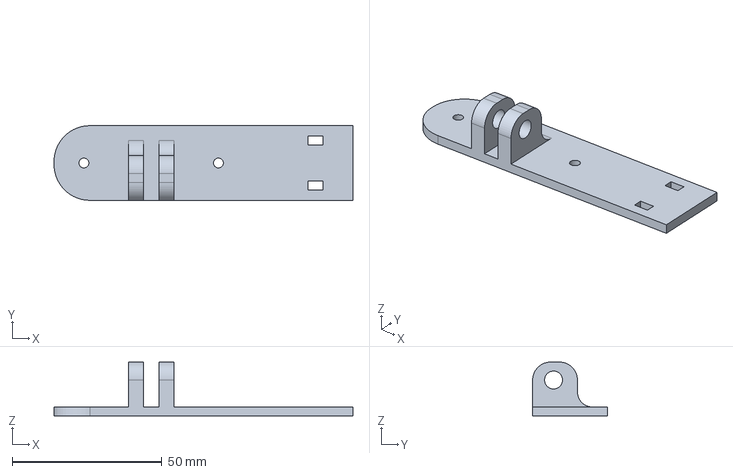
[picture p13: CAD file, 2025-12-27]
cad/realsense_camera_clamp.FCStd
100.0 x 25.0 x 18.0 mm

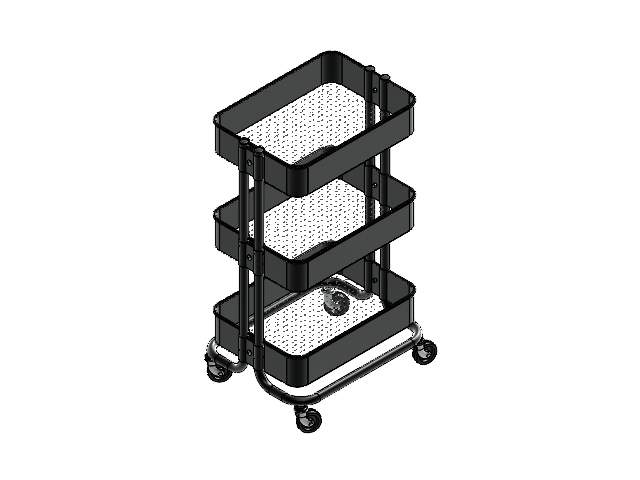
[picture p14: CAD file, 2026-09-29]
cad/raskog-storage-cart-1.snapshot.4/Raskog Assem/Raskog Assem.SLDASM
Bottom Stand x 2
Upper Stand x 2
Bottom Frame x 2
Wheel Holder x 4
Bearing Ring x 4
Wheel x 4
Top Bearing Ring x 4
Wheel Pin x 4
Caster Screw x 4
Caster Nut x 4
Backet Mount x 6
Backet Screw x 6
Backet Nut x 6

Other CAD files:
cad/REALSENSE_assembly.FCStd
cad/raskog-storage-cart-1.snapshot.4/Raskog Assem/Caster Wheel Assem.SLDASM
cad/back_plate-Body.stl
cad/raskog-storage-cart-1.snapshot.4/Raskog V1_Real 1.STEP
cad/raskog-storage-cart-1.snapshot.4/Raskog Assem/Backet Nut.SLDPRT
cad/raskog-storage-cart-1.snapshot.4/Raskog Assem/Backet Screw.SLDPRT
cad/raskog-storage-cart-1.snapshot.4/Raskog Assem/Bottom Frame.SLDPRT
cad/raskog-storage-cart-1.snapshot.4/Raskog Assem/Box 1.SLDPRT
cad/raskog-storage-cart-1.snapshot.4/Raskog Assem/Caster Nut.SLDPRT
cad/raskog-storage-cart-1.snapshot.4/Raskog Assem/Caster Screw.SLDPRT
cad/raskog-storage-cart-1.snapshot.4/Raskog Assem/Upper Stand.SLDPRT
cad/raskog-storage-cart-1.snapshot.4/Raskog Assem/Wheel Holder.SLDPRT
cad/raskog-storage-cart-1.snapshot.4/Raskog Assem/Wheel Pin.SLDPRT
cad/raskog-storage-cart-1.snapshot.4/Raskog Assem/Wheel.SLDPRT
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

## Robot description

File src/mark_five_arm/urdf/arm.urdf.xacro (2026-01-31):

<?xml version="1.0"?>
<robot xmlns:xacro="http://www.ros.org/wiki/xacro" name="mark_five_arm">

  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

  <xacro:property name="base_height" value="0.05" />
  <xacro:property name="base_radius" value="0.04" />

  <xacro:property name="shoulder_length" value="0.15" />
  <xacro:property name="shoulder_radius" value="0.02" />

  <xacro:property name="elbow_length" value="0.15" />
  <xacro:property name="elbow_radius" value="0.015" />

  <xacro:property name="wrist_length" value="0.08" />
  <xacro:property name="wrist_radius" value="0.01" />

  <xacro:property name="gripper_length" value="0.06" />
  <xacro:property name="gripper_width" value="0.03" />

  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
  <xacro:property name="base_limit" value="1.5708" />        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
  <xacro:property name="shoulder_limit" value="1.5708" />    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
  <xacro:property name="elbow_limit" value="1.5708" />       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
  <xacro:property name="wrist_pitch_limit" value="1.5708" /> 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
  <xacro:property name="wrist_roll_limit" value="1.5708" />  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
  <xacro:property name="gripper_limit" value="1.0472" />     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

  <xacro:macro name="cylinder_link" params="name length radius material">
    <link name="${name}">
      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
      <inertial>
        <origin xyz="0 0 ${length/2}" rpy="0 0 0"/>
        <mass value="0.1"/>
        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
      </inertial>
    </link>
  </xacro:macro>

  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

  <link name="arm_base_link">
    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
    <inertial>
      <origin xyz="0 0 ${base_height/2}" rpy="0 0 0"/>
      <mass value="0.5"/>
      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
    </inertial>
  </link>

  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

  <link name="base_rotate_link">
    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
    <inertial>
      <origin xyz="0 0 0.02" rpy="0 0 0"/>
      <mass value="0.2"/>
      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
    </inertial>
  </link>

  <joint name="base" type="revolute">
    <parent link="arm_base_link"/>
    <child link="base_rotate_link"/>
    <origin xyz="0 0 ${base_height}" rpy="0 0 0"/>
    <axis xyz="0 0 1"/>
    <limit lower="${-base_limit}" upper="${base_limit}" effort="10" velocity="1.0"/>
  </joint>

  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

  <xacro:cylinder_link name="shoulder_link" length="${shoulder_length}" radius="${shoulder_radius}" material="blue"/>

  <joint name="shoulder" type="revolute">
    <parent link="base_rotate_link"/>
    <child link="shoulder_link"/>
    <origin xyz="0 0 0.04" rpy="0 0 0"/>
    <axis xyz="0 1 0"/>
    <limit lower="${-shoulder_limit}" upper="${shoulder_limit}" effort="10" velocity="1.0"/>
  </joint>

  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

  <xacro:cylinder_link name="elbow_link" length="${elbow_length}" radius="${elbow_radius}" material="gray"/>

  <joint name="elbow" type="revolute">
    <parent link="shoulder_link"/>
    <child link="elbow_link"/>
    <origin xyz="0 0 ${shoulder_length}" rpy="0 0 0"/>
    <axis xyz="0 1 0"/>
    <limit lower="${-elbow_limit}" upper="${elbow_limit}" effort="10" velocity="1.0"/>
  </joint>

  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

  <xacro:cylinder_link name="wrist_pitch_link" length="${wrist_length}" radius="${wrist_radius}" material="orange"/>

  <joint name="wrist_pitch" type="revolute">
    <parent link="elbow_link"/>
    <child link="wrist_pitch_link"/>
    <origin xyz="0 0 ${elbow_length}" rpy="0 0 0"/>
    <axis xyz="0 1 0"/>
    <limit lower="${-wrist_pitch_limit}" upper="${wrist_pitch_limit}" effort="5" velocity="1.0"/>
  </joint>

  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

  <link name="wrist_roll_link">
    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
    <inertial>
      <origin xyz="0 0 0.02" rpy="0 0 0"/>
      <mass value="0.05"/>
      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
    </inertial>
  </link>

  <joint name="wrist_roll" type="revolute">
    <parent link="wrist_pitch_link"/>
    <child link="wrist_roll_link"/>
    <origin xyz="0 0 ${wrist_length}" rpy="0 0 0"/>
    <axis xyz="0 0 1"/>
    <limit lower="${-wrist_roll_limit}" upper="${wrist_roll_limit}" effort="5" velocity="1.0"/>
  </joint>

  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

  <link name="gripper_base_link">
    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
    <inertial>
      <origin xyz="0 0 0.02" rpy="0 0 0"/>
      <mass value="0.05"/>
      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
    </inertial>
  </link>

  <joint name="gripper" type="revolute">
    <parent link="wrist_roll_link"/>
    <child link="gripper_base_link"/>
    <origin xyz="0 0 0.04" rpy="0 0 0"/>
    <axis xyz="0 1 0"/>
    <limit lower="0.0" upper="${gripper_limit}" effort="5" velocity="1.0"/>
  </joint>

  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
  <link name="gripper_left_finger">
    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
  </link>

  <link name="gripper_right_finger">
    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
  </link>

  <joint name="gripper_left_finger_joint" type="fixed">
    <parent link="gripper_base_link"/>
    <child link="gripper_left_finger"/>
    <origin xyz="0 0 0.04" rpy="0 0 0"/>
  </joint>

  <joint name="gripper_right_finger_joint" type="fixed">
    <parent link="gripper_base_link"/>
    <child link="gripper_right_finger"/>
    <origin xyz="0 0 0.04" rpy="0 0 0"/>
  </joint>

  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
  <link name="end_effector_link"/>

  <joint name="end_effector_joint" type="fixed">
    <parent link="gripper_base_link"/>
    <child link="end_effector_link"/>
    <origin xyz="0 0 ${0.04 + gripper_length}" rpy="0 0 0"/>
  </joint>

</robot>

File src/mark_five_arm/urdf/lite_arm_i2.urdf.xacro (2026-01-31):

<?xml version="1.0"?>
<robot xmlns:xacro="http://www.ros.org/wiki/xacro" name="lite_arm_i2">

  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
  <xacro:property name="base_height" value="0.050" />       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
  <xacro:property name="base_radius" value="0.052" />       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
  <xacro:property name="upper_arm_length" value="0.2301" /> 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
  <xacro:property name="upper_arm_width" value="0.031" />   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
  <xacro:property name="upper_arm_height" value="0.006" />  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
  <xacro:property name="forearm_length" value="0.1803" />   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
  <xacro:property name="forearm_width" value="0.018" />     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
  <xacro:property name="forearm_height" value="0.006" />    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

  <xacro:property name="gripper_length" value="0.080" />    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
  <xacro:property name="gripper_finger_length" value="0.050" />  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
  <xacro:property name="base_lower" value="${-pi/2}" />     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
  <xacro:property name="base_upper" value="${pi/2}" />      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

  <xacro:property name="shoulder_lower" value="${-pi/4}" /> 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
  <xacro:property name="shoulder_upper" value="${pi/2}" />  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

  <xacro:property name="elbow_lower" value="${-pi/2}" />    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
  <xacro:property name="elbow_upper" value="${pi/2}" />     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

  <xacro:property name="gripper_lower" value="0.0" />       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
  <xacro:property name="gripper_upper" value="0.785" />     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

  <link name="arm_base_link">
    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
    <inertial>
      <origin xyz="0 0 ${base_height/2}" rpy="0 0 0"/>
      <mass value="0.5"/>
      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
    </inertial>
  </link>

  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

  <link name="base_rotate_link">
    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
    <inertial>
      <origin xyz="0 0 0.015" rpy="0 0 0"/>
      <mass value="0.15"/>
      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
    </inertial>
  </link>

  <joint name="base" type="revolute">
    <parent link="arm_base_link"/>
    <child link="base_rotate_link"/>
    <origin xyz="0 0 ${base_height}" rpy="0 0 0"/>
    <axis xyz="0 0 1"/>
    <limit lower="${base_lower}" upper="${base_upper}" effort="10.0" velocity="1.0"/>
    <dynamics damping="0.1" friction="0.1"/>
  </joint>

  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

  <link name="upper_arm_link">
    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
    <inertial>
      <origin xyz="${upper_arm_length/2} 0 0" rpy="0 0 0"/>
      <mass value="0.2"/>
      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
    </inertial>
  </link>

  <joint name="shoulder" type="revolute">
    <parent link="base_rotate_link"/>
    <child link="upper_arm_link"/>
    <origin xyz="0 0 0.03" rpy="0 0 0"/>
    <axis xyz="0 1 0"/>
    <limit lower="${shoulder_lower}" upper="${shoulder_upper}" effort="10.0" velocity="1.0"/>
    <dynamics damping="0.1" friction="0.1"/>
  </joint>

  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

  <link name="forearm_link">
    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
    <inertial>
      <origin xyz="${forearm_length/2} 0 0" rpy="0 0 0"/>
      <mass value="0.15"/>
      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
    </inertial>
  </link>

  <joint name="elbow" type="revolute">
    <parent link="upper_arm_link"/>
    <child link="forearm_link"/>
    <origin xyz="${upper_arm_length} 0 0" rpy="0 0 0"/>
    <axis xyz="0 1 0"/>
    <limit lower="${elbow_lower}" upper="${elbow_upper}" effort="10.0" velocity="1.0"/>
    <dynamics damping="0.1" friction="0.1"/>
  </joint>

  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

  <link name="gripper_base_link">
    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
    <inertial>
      <origin xyz="0.02 0 0" rpy="0 0 0"/>
      <mass value="0.05"/>
      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
    </inertial>
  </link>

  <joint name="gripper" type="revolute">
    <parent link="forearm_link"/>
    <child link="gripper_base_link"/>
    <origin xyz="${forearm_length} 0 0" rpy="0 0 0"/>
    <axis xyz="0 1 0"/>
    <limit lower="${gripper_lower}" upper="${gripper_upper}" effort="5.0" velocity="1.0"/>
    <dynamics damping="0.05" friction="0.05"/>
  </joint>

  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
  <link name="gripper_left_finger">
    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
    <inertial>
      <origin xyz="${gripper_finger_length/2} 0.02 0" rpy="0 0 0"/>
      <mass value="0.01"/>
      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
    </inertial>
  </link>

  <joint name="gripper_left_finger_joint" type="fixed">
    <parent link="gripper_base_link"/>
    <child link="gripper_left_finger"/>
    <origin xyz="0.04 0 0" rpy="0 0 0"/>
  </joint>

  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
  <link name="gripper_right_finger">
    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
    <inertial>
      <origin xyz="${gripper_finger_length/2} -0.02 0" rpy="0 0 0"/>
      <mass value="0.01"/>
      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
    </inertial>
  </link>

  <joint name="gripper_right_finger_joint" type="fixed">
    <parent link="gripper_base_link"/>
    <child link="gripper_right_finger"/>
    <origin xyz="0.04 0 0" rpy="0 0 0"/>
  </joint>

  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

  <link name="end_effector_link"/>

  <joint name="end_effector_joint" type="fixed">
    <parent link="gripper_base_link"/>
    <child link="end_effector_link"/>
    <origin xyz="${0.04 + gripper_finger_length} 0 0" rpy="0 0 0"/>
  </joint>

  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
  <link name="world"/>

  <joint name="world_to_base" type="fixed">
    <parent link="world"/>
    <child link="arm_base_link"/>
    <origin xyz="0 0 0" rpy="0 0 0"/>
  </joint>

</robot>

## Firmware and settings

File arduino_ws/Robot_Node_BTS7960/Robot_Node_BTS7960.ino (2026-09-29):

/*
 * Robot_Node_BTS7960.ino  —  Closed-loop differential drive
 *
 * Per-wheel PI velocity control (encoder feedback) with feedforward,
 * PWM slew-rate limiting, and matched 3.9 kHz PWM on all motor pins.
 *
 * Serial Protocol:
 *   RX: "v,<linear_x>,<angular_z>\n"   (from ROS serial_bridge)
 *   TX: "t,<left_ticks>,<right_ticks>\n" (to ROS serial_bridge)
 *
 * Wiring — REV B (pins 4 and 7 SWAPPED vs REV A):
 *   Left  BTS7960: RPWM→7, LPWM→5, R_EN→6,  L_EN→4
 *   Right BTS7960: RPWM→8, LPWM→9, R_EN→10, L_EN→11
 *   Left  encoder: A→21, B→20
 *   Right encoder: A→3,  B→2
 *
 * Why the swap: pin 4 is on Timer0, whose prescaler can't change without
 * breaking millis(). With RPWM on 7, all four PWM pins sit on Timers 2/3/4,
 * which are retimed to 3.92 kHz (default 490 Hz is rough and audible;
 * BTS7960 is rated to 25 kHz).
 */

#define SERIAL_BAUD      115200
#define LOOP_INTERVAL    30     // ms between control updates + tick publishes

// ── Pin definitions (REV B) ───────────────────────────────────────────────────

#define RPWM_LEFT   7
#define LPWM_LEFT   5
#define R_EN_LEFT   6
#define L_EN_LEFT   4

#define RPWM_RIGHT  8
#define LPWM_RIGHT  9
#define R_EN_RIGHT  10
#define L_EN_RIGHT  11

#define ENC_IN_LEFT_A   21
#define ENC_IN_LEFT_B   20
#define ENC_IN_RIGHT_A  3
#define ENC_IN_RIGHT_B  2

// ── Physical parameters ───────────────────────────────────────────────────────

const double WHEEL_BASE = 0.36;   // meters, center-to-center of wheels

// Per-wheel calibration (must match odometry.yaml — 2x A-channel CHANGE decoder)
// The ~8% L/R difference is real hardware asymmetry in the right encoder.
const double TICKS_PER_METER_LEFT  = 4594.0;
const double TICKS_PER_METER_RIGHT = 4255.0;

// ── Control parameters ────────────────────────────────────────────────────────

// Feedforward: PWM ≈ K_FF * |vel| + FF_OFFSET (gets the output near the right
// value immediately; the PI loop corrects the residual). Stall is around
// PWM 60 unloaded — the integrator winds through stiction if FF undershoots.
const double K_FF      = 278.0;
const double FF_OFFSET = 52.0;

// PI gains (PWM counts per m/s of error, PWM counts per m of integrated error)
const double KP_VEL = 150.0;
const double KI_VEL = 600.0;
const double INTEGRAL_MAX = 0.1;  // clamp so KI * integral ≤ 60 PWM counts

// Low-pass filter on measured wheel velocity (1 tick / 30 ms ≈ 0.007 m/s
// quantization). alpha = weight of the newest sample.
const double VEL_FILTER_ALPHA = 0.4;

const int PWM_MAX  = 160;  // ~63% duty; v ≈ 0.39 m/s open-loop equivalent
const int SLEW_MAX = 10;   // max PWM change per 30 ms loop (0→160 in ~0.5 s)

const double V_DEADBAND = 0.01;  // m/s; below this, target is treated as stop

// ── Encoder state (modified by ISRs) ─────────────────────────────────────────

volatile int16_t left_wheel_tick_count  = 0;
volatile int16_t right_wheel_tick_count = 0;

// ── Runtime state ─────────────────────────────────────────────────────────────

double velLeftTarget  = 0.0;   // m/s, positive = forward
double velRightTarget = 0.0;

double velLeftMeas  = 0.0;     // filtered measured wheel velocity, m/s
double velRightMeas = 0.0;

double integralLeft  = 0.0;    // integrated velocity error, m
double integralRight = 0.0;

int pwmLeftOut  = 0;           // signed PWM currently applied (after slew)
int pwmRightOut = 0;

int16_t prevTicksLeft  = 0;    // tick snapshot from previous control loop
int16_t prevTicksRight = 0;

unsigned long lastCmdVelReceived = 0;
unsigned long previousMillis     = 0;

char    cmdBuf[48];
uint8_t cmdLen = 0;

// ── Encoder ISRs ──────────────────────────────────────────────────────────────
// CHANGE on A channel only. When A changes, B has been stable for ~90° of
// rotation (mid-phase), so direction reads are reliable with no timing races.
// The B channel is not used as an interrupt source — its short pulses caused
// missed edges and asymmetric counts on the right encoder.
// Forward motion DECREMENTS the raw count; publishTicks() and the control
// loop both negate, so ROS and the PI loop see forward as positive.

void right_wheel_tick() {
  boolean a = digitalRead(ENC_IN_RIGHT_A);
  boolean b = digitalRead(ENC_IN_RIGHT_B);
  // A leads B during physical forward: A rising + B low, or A falling + B high
  boolean forward = a ? !b : b;
  if (forward) {
    right_wheel_tick_count = (right_wheel_tick_count == -32768) ? 32767  : right_wheel_tick_count - 1;
  } else {
    right_wheel_tick_count = (right_wheel_tick_count == 32767)  ? -32768 : right_wheel_tick_count + 1;
  }
}

void left_wheel_tick() {
  boolean a = digitalRead(ENC_IN_LEFT_A);
  boolean b = digitalRead(ENC_IN_LEFT_B);
  // Left motor inverted — B leads A during physical forward: A rising + B high, or A falling + B low
  boolean forward = a ? b : !b;
  if (forward) {
    left_wheel_tick_count = (left_wheel_tick_count == -32768) ? 32767  : left_wheel_tick_count - 1;
  } else {
    left_wheel_tick_count = (left_wheel_tick_count == 32767)  ? -32768 : left_wheel_tick_count + 1;
  }
}

// ── Motor helpers ─────────────────────────────────────────────────────────────

void set_motor(int rpwm_pin, int lpwm_pin, int signed_pwm) {
  int mag = constrain(abs(signed_pwm), 0, 255);
  if (signed_pwm >= 0) {
    analogWrite(rpwm_pin, mag);
    analogWrite(lpwm_pin, 0);
  } else {
    analogWrite(rpwm_pin, 0);
    analogWrite(lpwm_pin, mag);
  }
}

// ── Control ───────────────────────────────────────────────────────────────────

double feedforward(double vel) {
  if (vel > 0)  return  K_FF * vel + FF_OFFSET;
  if (vel < 0)  return  K_FF * vel - FF_OFFSET;
  return 0.0;
}

// One PI update for one wheel. Returns the new signed PWM (pre-slew).
int velocityPi(double target, double measured, double dt, double &integral) {
  if (target == 0.0) {
    // Commanded stop: no PI hunting around zero, just ramp the PWM down
    // (the slew limiter provides the ramp). Reset integrator for a clean
    // next start.
    integral = 0.0;
    return 0;
  }

  double error = target - measured;
  double u = feedforward(target) + KP_VEL * error + KI_VEL * integral;

  // Anti-windup: integrate only if output is unsaturated, or the error is
  // pulling the output back out of saturation.
  bool saturated = (u > PWM_MAX) || (u < -PWM_MAX);
  if (!saturated || (error > 0) != (u > 0)) {
    integral = constrain(integral + error * dt, -INTEGRAL_MAX, INTEGRAL_MAX);
  }

  return constrain((int)u, -PWM_MAX, PWM_MAX);
}

int slewLimit(int current, int requested) {
  return constrain(requested, current - SLEW_MAX, current + SLEW_MAX);
}

void controlUpdate(double dt) {
  noInterrupts();
  int16_t lt = left_wheel_tick_count;
  int16_t rt = right_wheel_tick_count;
  interrupts();

  // int16 subtraction handles counter wraparound; negate so forward = positive
  double dLeft  = -(double)((int16_t)(lt - prevTicksLeft));
  double dRight = -(double)((int16_t)(rt - prevTicksRight));
  prevTicksLeft  = lt;
  prevTicksRight = rt;

  double vLeftRaw  = dLeft  / TICKS_PER_METER_LEFT  / dt;
  double vRightRaw = dRight / TICKS_PER_METER_RIGHT / dt;
  velLeftMeas  += VEL_FILTER_ALPHA * (vLeftRaw  - velLeftMeas);
  velRightMeas += VEL_FILTER_ALPHA * (vRightRaw - velRightMeas);

  int pwmLeftReq  = velocityPi(velLeftTarget,  velLeftMeas,  dt, integralLeft);
  int pwmRightReq = velocityPi(velRightTarget, velRightMeas, dt, integralRight);

  pwmLeftOut  = slewLimit(pwmLeftOut,  pwmLeftReq);
  pwmRightOut = slewLimit(pwmRightOut, pwmRightReq);

  set_motor(RPWM_LEFT,  LPWM_LEFT,  pwmLeftOut);
  set_motor(RPWM_RIGHT, LPWM_RIGHT, pwmRightOut);
}

// ── Velocity command ──────────────────────────────────────────────────────────

void processCmdVel(double linear_x, double angular_z) {
  lastCmdVelReceived = millis();

  // Standard differential-drive kinematics.
  // angular_z > 0 = CCW = turn left → left wheel backward, right wheel forward.
  double leftVel  = linear_x - (WHEEL_BASE / 2.0) * angular_z;
  double rightVel = linear_x + (WHEEL_BASE / 2.0) * angular_z;

  velLeftTarget  = (fabs(leftVel)  < V_DEADBAND) ? 0.0 : leftVel;
  velRightTarget = (fabs(rightVel) < V_DEADBAND) ? 0.0 : rightVel;
}

// ── Serial ────────────────────────────────────────────────────────────────────

void parseCommand(const char *s) {
  if (s[0] != 'v' || s[1] != ',') return;
  char *end;
  double linear_x = strtod(s + 2, &end);
  if (*end != ',') return;
  double angular_z = strtod(end + 1, NULL);
  processCmdVel(linear_x, angular_z);
}

// Fixed buffer, parsed as soon as a full line arrives — no String heap churn,
// and back-to-back commands in one serialEvent() can't clobber each other.
void serialEvent() {
  while (Serial.available()) {
    char c = (char)Serial.read();
    if (c == '\n') {
      cmdBuf[cmdLen] = '\0';
      parseCommand(cmdBuf);
      cmdLen = 0;
    } else if (c != '\r') {
      if (cmdLen < sizeof(cmdBuf) - 1) {
        cmdBuf[cmdLen++] = c;
      } else {
        cmdLen = 0;  // overlong garbage line: discard and resync at next '\n'
      }
    }
  }
}

void publishTicks() {
  noInterrupts();
  int16_t lt = left_wheel_tick_count;
  int16_t rt = right_wheel_tick_count;
  interrupts();
  Serial.print("t,");
  Serial.print(-lt);
  Serial.print(",");
  Serial.println(-rt);
}

// ── Setup / Loop ──────────────────────────────────────────────────────────────

void setup() {
  // Enable both half-bridges on each BTS7960
  pinMode(R_EN_LEFT,  OUTPUT); digitalWrite(R_EN_LEFT,  HIGH);
  pinMode(L_EN_LEFT,  OUTPUT); digitalWrite(L_EN_LEFT,  HIGH);
  pinMode(R_EN_RIGHT, OUTPUT); digitalWrite(R_EN_RIGHT, HIGH);
  pinMode(L_EN_RIGHT, OUTPUT); digitalWrite(L_EN_RIGHT, HIGH);

  set_motor(RPWM_LEFT,  LPWM_LEFT,  0);
  set_motor(RPWM_RIGHT, LPWM_RIGHT, 0);

  // Retime motor PWM from the 490 Hz default to 3.92 kHz (phase-correct,
  // prescaler 64 → 8). Timer0 (millis) is untouched — no motor pin uses it.
  TCCR2B = (TCCR2B & 0b11111000) | 0x02;  // pin 9  (right LPWM)
  TCCR3B = (TCCR3B & 0b11111000) | 0x02;  // pin 5  (left LPWM)
  TCCR4B = (TCCR4B & 0b11111000) | 0x02;  // pins 7, 8 (left/right RPWM)

  // INPUT_PULLUP on all encoder pins reduces electrical noise
  pinMode(ENC_IN_LEFT_A,  INPUT_PULLUP);
  pinMode(ENC_IN_LEFT_B,  INPUT_PULLUP);
  pinMode(ENC_IN_RIGHT_A, INPUT_PULLUP);
  pinMode(ENC_IN_RIGHT_B, INPUT_PULLUP);

  // A-channel CHANGE only — B read inside ISR, not used as interrupt source
  attachInterrupt(digitalPinToInterrupt(ENC_IN_RIGHT_A), right_wheel_tick, CHANGE);
  attachInterrupt(digitalPinToInterrupt(ENC_IN_LEFT_A),  left_wheel_tick,  CHANGE);

  Serial.begin(SERIAL_BAUD);
}

void loop() {
  unsigned long now = millis();
  if (now - previousMillis >= LOOP_INTERVAL) {
    double dt = (now - previousMillis) / 1000.0;
    previousMillis = now;

    // Safety stop: zero targets if no command received for 1 second
    if (now - lastCmdVelReceived > 1000) {
      velLeftTarget  = 0.0;
      velRightTarget = 0.0;
    }

    controlUpdate(dt);
    publishTicks();
  }
}

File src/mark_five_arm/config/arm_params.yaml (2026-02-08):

/**:
  ros__parameters:
    # PCA9685 I2C Configuration
    i2c_address: 0x40  # Default PCA9685 address
    pwm_frequency: 50  # 50 Hz for standard servos

    # Number of joints
    # Original Lite Arm i2 has 3 servos (base, shoulder, elbow)
    # Set to 4 if you add a gripper servo
    num_joints: 3

    # Joint names (Lite Arm i2 - 3 DOF parallel linkage design)
    # Add 'gripper' to this list if you install a gripper servo
    joint_names: ['base', 'shoulder', 'elbow']

    # Publishing rate for joint states (Hz)
    publish_rate: 10.0

    # =================================================================
    # Per-Joint Configuration
    # =================================================================
    # For each joint, configure:
    #   - channel: PCA9685 channel (0-15)
    #   - min_angle: Minimum angle in radians
    #   - max_angle: Maximum angle in radians
    #   - min_pwm: PWM value (0-4095) at min_angle
    #   - max_pwm: PWM value (0-4095) at max_angle
    #   - home_angle: Home/neutral position in radians
    #   - inverted: Reverse servo direction if true
    #
    # PWM Calibration Guide:
    #   Most hobby servos: 1000-2000 (typical range)
    #   Some servos: 500-2500 (extended range, check datasheet)
    #   Center position: ~1500
    # =================================================================

    # Base Joint (rotation around vertical axis)
    # Servo: Power HD 1501 MG
    # Calibrated PWM range: 690-2600μs (~180° travel)
    base:
      channel: 0
      min_angle: -1.5708  # -90 degrees in radians
      max_angle: 1.5708   # +90 degrees in radians
      min_pwm: 690        # PWM at -90°
      max_pwm: 2600       # PWM at +90°
      home_angle: 0.0     # 0° (center)
      inverted: false

    # Shoulder Joint (first vertical rotation)
    # Servo: Power HD 1501 MG
    # Calibrated PWM range: 900-2000μs
    shoulder:
      channel: 1
      min_angle: -1.5708  # -90 degrees
      max_angle: 1.5708   # +90 degrees
      min_pwm: 900        # PWM at min
      max_pwm: 2000       # PWM at max
      home_angle: 0.0     # center
      inverted: false

    # Elbow Joint (forearm)
    # Servo: Power HD 1501 MG
    # Calibrated PWM range: 900-2350μs
    elbow:
      channel: 2
      min_angle: -1.5708  # -90 degrees
      max_angle: 1.5708   # +90 degrees
      min_pwm: 900        # PWM at min
      max_pwm: 2350       # PWM at max
      home_angle: 0.0     # center
      inverted: false

    # =================================================================
    # OPTIONAL: Gripper (uncomment if you add a gripper servo)
    # =================================================================
    # To enable gripper:
    # 1. Change num_joints to 4
    # 2. Add 'gripper' to joint_names list
    # 3. Uncomment the gripper section below
    #
    # gripper:
    #   channel: 3
    #   min_angle: 0.0      # Fully open (0°)
    #   max_angle: 1.0472   # Closed (60°)
    #   min_pwm: 1000       # PWM for open
    #   max_pwm: 2000       # PWM for closed
    #   home_angle: 0.5236  # Half-open (30°)
    #   inverted: false

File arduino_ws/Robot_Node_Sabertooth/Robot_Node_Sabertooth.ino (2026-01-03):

/*
 * Robot_Node_Sabertooth.ino (Simple Serial Protocol)
 *
 * Description: Arduino node for Mark Five AMR using Sabertooth 2x12 motor driver.
 *              Uses simple serial protocol instead of ros2arduino (memory efficient).
 *              Publishes encoder ticks and receives velocity commands via serial.
 *
 * Motor Driver: Sabertooth 2x12 v1.00 (Packetized Serial Mode)
 * Library: Dimension Engineering Sabertooth Arduino Library
 *
 * DIP Switches: OFF OFF ON ON ON ON (Packetized Serial, Address 128)
 *
 * Serial Protocol:
 *   TX (Arduino sends):  "t,<left_ticks>,<right_ticks>\n"
 *   RX (Arduino receives): "v,<linear_x>,<angular_z>\n"
 *
 * Wiring:
 *   Pin 18 (TX1) --> Sabertooth S1
 *   GND --> Sabertooth 0V
 *   Encoders on pins 2, 3, 20, 21
 *
 * ROS2 Bridge: Run the serial_bridge node on the host to convert to ROS2 topics.
 *
 * Based on original Robot_Node.ino for L293DNE H-Bridge.
 * Reference: Automatic Addison, Practical Robotics in C++
 */

#include <Sabertooth.h>

// Serial configuration
#define SERIAL_BAUD 115200
#define PUBLISH_INTERVAL 30  // ms

// Sabertooth at address 128, using Serial1 (Pin 18 TX on Mega)
Sabertooth ST(128, Serial1);

////////////////// Tick Data Publishing Variables and Constants ///////////////

// Encoder output to Arduino Interrupt pin. Tracks the tick count.
#define ENC_IN_LEFT_A 21
#define ENC_IN_RIGHT_A 3

// Other encoder output to Arduino to keep track of wheel direction
#define ENC_IN_LEFT_B 20
#define ENC_IN_RIGHT_B 2

// True = Forward; False = Reverse
boolean Direction_left = true;
boolean Direction_right = true;

// Min/max values for 16-bit integers (range of 65,535)
const int encoder_minimum = -32768;
const int encoder_maximum = 32767;

// Keep track of the number of wheel ticks
volatile int16_t right_wheel_tick_count = 0;
volatile int16_t left_wheel_tick_count = 0;

// Time interval for measurements in milliseconds
unsigned long previousMillis = 0;
unsigned long currentMillis = 0;

////////////////// Motor Controller Variables and Constants ///////////////////

// Number of ticks per wheel revolution
const int TICKS_PER_REVOLUTION = 540;

// Wheel radius in meters
const double WHEEL_RADIUS = 0.055;

// Distance from center of left tire to center of right tire in meters
const double WHEEL_BASE = 0.14;

// Number of ticks a wheel makes moving a linear distance of 1 meter
const double TICKS_PER_METER = 3125;

// Proportional constant for PWM-Linear Velocity relationship
const int K_P = 278;

// Y-intercept for PWM-Linear Velocity relationship
const int b = 52;

// Correction multiplier for drift
const int DRIFT_MULTIPLIER = 120;

// Turning PWM output (Sabertooth uses -127 to 127)
const int PWM_TURN = 40;

// Set minimum and maximum limits for the PWM values
const int PWM_MIN = 30;  // Minimum to overcome friction
const int PWM_MAX = 50;  // Limit max speed

// Velocity and PWM variables for each wheel
double velLeftWheel = 0;
double velRightWheel = 0;
double pwmLeftReq = 0;
double pwmRightReq = 0;

// Record the time that the last velocity command was received
unsigned long lastCmdVelReceived = 0;

// Serial receive buffer
String inputString = "";
boolean stringComplete = false;

/////////////////////// Tick Data Publishing Functions ////////////////////////

void right_wheel_tick() {
  int val = digitalRead(ENC_IN_RIGHT_B);

  if (val == LOW) {
    Direction_right = false; // Reverse
  } else {
    Direction_right = true;  // Forward
  }

  if (Direction_right) {
    if (right_wheel_tick_count == encoder_maximum) {
      right_wheel_tick_count = encoder_minimum;
    } else {
      right_wheel_tick_count++;
    }
  } else {
    if (right_wheel_tick_count == encoder_minimum) {
      right_wheel_tick_count = encoder_maximum;
    } else {
      right_wheel_tick_count--;
    }
  }
}

void left_wheel_tick() {
  int val = digitalRead(ENC_IN_LEFT_B);

  if (val == LOW) {
    Direction_left = true;  // Reverse
  } else {
    Direction_left = false; // Forward
  }

  if (Direction_left) {
    if (left_wheel_tick_count == encoder_maximum) {
      left_wheel_tick_count = encoder_minimum;
    } else {
      left_wheel_tick_count++;
    }
  } else {
    if (left_wheel_tick_count == encoder_minimum) {
      left_wheel_tick_count = encoder_maximum;
    } else {
      left_wheel_tick_count--;
    }
  }
}

/////////////////////// Motor Controller Functions ////////////////////////////

void calc_vel_left_wheel() {
  static unsigned long prevTime = 0;
  static int prevLeftCount = 0;

  int numOfTicks = (65535 + left_wheel_tick_count - prevLeftCount) % 65535;

  if (numOfTicks > 10000) {
    numOfTicks = 0 - (65535 - numOfTicks);
  }

  unsigned long currentTime = millis();
  if (currentTime > prevTime) {
    velLeftWheel = (double)numOfTicks / TICKS_PER_METER / ((currentTime - prevTime) / 1000.0);
  }
  prevLeftCount = left_wheel_tick_count;
  prevTime = currentTime;
}

void calc_vel_right_wheel() {
  static unsigned long prevTime = 0;
  static int prevRightCount = 0;

  int numOfTicks = (65535 + right_wheel_tick_count - prevRightCount) % 65535;

  if (numOfTicks > 10000) {
    numOfTicks = 0 - (65535 - numOfTicks);
  }

  unsigned long currentTime = millis();
  if (currentTime > prevTime) {
    velRightWheel = (double)numOfTicks / TICKS_PER_METER / ((currentTime - prevTime) / 1000.0);
  }
  prevRightCount = right_wheel_tick_count;
  prevTime = currentTime;
}

void processCmdVel(double linear_x, double angular_z) {
  lastCmdVelReceived = millis();

  // Scale linear velocity to PWM (-127 to 127 for Sabertooth)
  // Apply offset 'b' with proper sign for forward/backward motion
  if (linear_x >= 0) {
    pwmLeftReq = K_P * linear_x + b;
    pwmRightReq = K_P * linear_x + b;
  } else {
    pwmLeftReq = K_P * linear_x - b;
    pwmRightReq = K_P * linear_x - b;
  }

  if (angular_z != 0.0) {
    // Note: Signs inverted to match physical motor/encoder configuration
    if (angular_z > 0.0) {  // Turn left
      pwmLeftReq = PWM_TURN;
      pwmRightReq = -PWM_TURN;
    } else {  // Turn right
      pwmLeftReq = -PWM_TURN;
      pwmRightReq = PWM_TURN;
    }
  } else {  // Go straight - apply drift correction
    static double prevDiff = 0;
    static double prevPrevDiff = 0;
    double currDifference = velLeftWheel - velRightWheel;
    double avgDifference = (prevDiff + prevPrevDiff + currDifference) / 3;
    prevPrevDiff = prevDiff;
    prevDiff = currDifference;

    pwmLeftReq -= (int)(avgDifference * DRIFT_MULTIPLIER);
    pwmRightReq += (int)(avgDifference * DRIFT_MULTIPLIER);
  }

  // Handle low PWM values
  if (abs(pwmLeftReq) < PWM_MIN) {
    pwmLeftReq = 0;
  }
  if (abs(pwmRightReq) < PWM_MIN) {
    pwmRightReq = 0;
  }
}
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

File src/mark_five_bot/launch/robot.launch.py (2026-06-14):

"""
Robot Launch File (for Jetson Nano in distributed mode)

Launches sensor and actuation nodes on the robot:
- robot_state_publisher (URDF TF)
- serial_bridge (Arduino communication for motors)
- odometry (encoder-based odometry with per-wheel calibration)
- IMU (ICM-20948 9-DOF sensor)
- EKF filter (sensor fusion - odometry + IMU)
- RealSense camera (with mode switching for laser/visual SLAM)
- RTAB-Map SLAM (optional, runs locally to avoid WiFi bandwidth bottleneck)

The workstation runs Nav2 and RViz. When slam:=rtab, SLAM also runs here.

Usage:
  # Laser SLAM mode (workstation handles SLAM)
  ros2 launch mark_five_bot robot.launch.py

  # Visual SLAM on Jetson (avoids sending raw RGB-D over WiFi)
  ros2 launch mark_five_bot robot.launch.py camera_mode:=visual_slam slam:=rtab

  # Without camera
  ros2 launch mark_five_bot robot.launch.py camera:=false

  # Without IMU
  ros2 launch mark_five_bot robot.launch.py imu:=false
"""

from launch import LaunchDescription
from launch.actions import DeclareLaunchArgument, IncludeLaunchDescription
from launch.conditions import IfCondition
from launch.launch_description_sources import PythonLaunchDescriptionSource
from launch.substitutions import LaunchConfiguration, PythonExpression
from launch_ros.actions import Node
from ament_index_python.packages import get_package_share_directory
import os


def generate_launch_description():
    # Get package share directories
    pkg_share = get_package_share_directory('mark_five_bot')
    description_share = get_package_share_directory('mark_five_description')

    # Path to URDF
    urdf_file = os.path.join(description_share, 'urdf', 'robot.urdf')

    # Declare launch arguments
    camera_arg = DeclareLaunchArgument(
        'camera',
        default_value='true',
        description='Launch RealSense camera'
    )

    camera_mode_arg = DeclareLaunchArgument(
        'camera_mode',
        default_value='laser_scan',
        description='Camera mode: laser_scan (424x240@15fps) or visual_slam (640x480@30fps)'
    )

    imu_arg = DeclareLaunchArgument(
        'imu',
        default_value='true',
        description='Launch ICM-20948 IMU sensor'
    )

    slam_arg = DeclareLaunchArgument(
        'slam',
        default_value='none',
        description='SLAM to run on Jetson: none or rtab'
    )

    # Read URDF file
    with open(urdf_file, 'r') as f:
        robot_description = f.read()

    # Robot state publisher
    robot_state_publisher_node = Node(
        package='robot_state_publisher',
        executable='robot_state_publisher',
        name='robot_state_publisher',
        output='screen',
        parameters=[{
            'robot_description': robot_description,
        }],
    )

    # Serial communication with Arduino
    serial_launch = IncludeLaunchDescription(
        PythonLaunchDescriptionSource(
            os.path.join(pkg_share, 'launch', 'serial.launch.py')
        ),
    )

    # Odometry
    odometry_launch = IncludeLaunchDescription(
        PythonLaunchDescriptionSource(
            os.path.join(pkg_share, 'launch', 'odometry.launch.py')
        ),
    )

    # IMU (ICM-20948 9-DOF sensor - conditional)
    imu_launch = IncludeLaunchDescription(
        PythonLaunchDescriptionSource(
            os.path.join(pkg_share, 'launch', 'imu.launch.py')
        ),
        condition=IfCondition(LaunchConfiguration('imu')),
    )

    # EKF for sensor fusion (fuses wheel odometry + IMU)
    ekf_launch = IncludeLaunchDescription(
        PythonLaunchDescriptionSource(
            os.path.join(pkg_share, 'launch', 'ekf.launch.py')
        ),
    )

    # Camera (conditional)
    camera_launch = IncludeLaunchDescription(
        PythonLaunchDescriptionSource(
            os.path.join(pkg_share, 'launch', 'camera.launch.py')
        ),
        condition=IfCondition(LaunchConfiguration('camera')),
        launch_arguments={
            'mode': LaunchConfiguration('camera_mode'),
        }.items(),
    )

    # RTAB-Map SLAM on Jetson (optional — avoids sending raw RGB-D over WiFi)
    rtabmap_launch = IncludeLaunchDescription(
        PythonLaunchDescriptionSource(
            os.path.join(pkg_share, 'launch', 'rtabmap_slam.launch.py')
        ),
        condition=IfCondition(
            PythonExpression(["'", LaunchConfiguration('slam'), "' == 'rtab'"])
        ),
    )

    return LaunchDescription([
        camera_arg,
        camera_mode_arg,
        imu_arg,
        slam_arg,
        robot_state_publisher_node,
        serial_launch,
        odometry_launch,
        imu_launch,
        ekf_launch,
        camera_launch,
        rtabmap_launch,
    ])

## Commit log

2024-04-21 Arduino code to read locomate using encoder data
2024-08-05 Added classes for Motor and PID controllers
2024-08-10 Tested encoder feedback and motor driver
2025-12-24 Added placeholder urdf and created launch file
    [robot.urdf]
2025-12-24 Updated URDF for accurate representation
    [robot.urdf]
2025-12-24 Developed and tested Odometry node
2025-12-25 Swapped L293D with Sabertooth motor driver
    [Robot_Node_Sabertooth.ino, test_motors.ino, test_sabertooth_minimal.ino]
2025-12-25 Reduced PWM, marky_root fix, update launchh files to include teleop
    [Robot_Node_Sabertooth.ino]
2025-12-27 Added realsense camera packages and created launch file
    [robot.urdf]
2025-12-27 Design files for realsense clamp
    [REALSENSE_assembly.FCStd, realsense_camera_clamp-Body.stl, realsense_camera_clamp.FCStd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]
2025-12-27 Tweak URDF, camera configs
    [robot.urdf]
2025-12-29 Migrated codebase to ROS2 Jazzy and tested nodes
    [robot_params.yaml]
2025-12-31 Integrated Slam toolbox framework
2025-12-31 Bug fixes during slam testing
    [camera.launch.py, navigation.launch.py]
2026-01-02 switched cmd_vel to /cmd_vel_smoothed
2026-01-02 Fixed cmd_vel feedback loop
    [Robot_Node_Sabertooth.ino, serial_bridge.py]
2026-01-02 switched to Cyclone DDS
2026-01-03 Fixed inverted odometry
2026-01-03 Calibrated Wheel ticks
2026-01-03 Seperated ticks per meter for individual wheels
2026-01-04 Tuned SLAM params, installed EKF for odometry filtering
2026-01-08 Added IMU code
    [robot.urdf, robot_localization.yaml]
2026-01-08 Replaced BNO085 with ICM20948
    [robot.urdf, robot_localization.yaml]
2026-01-08 Install IMU driver
2026-01-10 Filter IMU data, jitter fix
    [robot_localization.yaml]
2026-01-11 Added RTAB mapping package
    [robot_localization_high_slip.yaml]
2026-01-19 fixed Rtabmap topic discrepency
    [rtabmap_slam.launch.py]
2026-01-27 Added node for the arm
2026-02-08 Servo calibrated
2026-03-18 Updated URDF with new chassis
    [robot.urdf]
2026-03-18 Add STL files
    [battery_holder-Body.stl, robot_chassis_v6.stl]
2026-03-18 Created custom IMU package
2026-05-24 Swapped Sabertooth with BTS7960
    [robot.urdf, robot_params.yaml]
2026-05-24 Fixed python test script
    [test_serial.py]
2026-05-24 Fixed python test script to only respond to keyboard input
    [test_bts7960.ino, test_serial.py]
2026-05-24 Fixed pinout and motor direction
    [Robot_Node_BTS7960.ino, test_bts7960.ino, test_serial.py]
2026-05-27 sucessful testing of motor driver
2026-05-27 Update PWM params
2026-06-07 Updated URDF and integrated IMU back in
    [robot.urdf]
2026-06-14 Odometry config tuning (#11)
    * Updated pose values
    * Fix PWM bugs
    * Simplify motor controls to debug PWM issue
    * Fix velocity sign
    * Undo velcity sign change
    * Fix Encoder sign
    * swapped Encoders
    * Encoder tuning
    * Encoder tuning
    * Encoder tuning
    * Camera FPS reduction
    [back_plate-Body.stl, back_plate.FCStd, robot.urdf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]
2026-06-14 Update ros2_icm20948 submodule with Jetson Nano I2C patch
    [robot_localization.yaml]
2026-06-14 Fix: Velocity command not published for visual SLAM
    [camera.launch.py]
2026-09-29 Camera stream invert
2026-09-29 Update EKF frequency
    [robot_localization.yaml]
2026-09-29 Run everything in Jetson
2026-09-29 Arduino motor driver code update, slam improvements, Lidar drivers
    [robot_localization.yaml]
2026-09-29 Urdf updates for lidar
    [robot.urdf]
2026-09-29 Fixed lidar port issue
    [lidar.launch.py]
2026-09-29 fixed imu and lidar crop angle
    [lidar.launch.py]
2026-09-29 Tweaked Lidar cutoff angles
2026-09-29 Updated URDF for cart
    [Backet Mount.SLDPRT, Backet Nut.SLDPRT, Backet Screw.SLDPRT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]
2026-09-29 Tweaked URDF camera and lidar pose
    [robot.urdf]
2026-09-29 Lidar clamp files
    [LD19Clamp-Clamp1_v2.stl, LD19Clamp-Clamp2_LidarHolder_v3.stl, LD19Clamp.FCStd]
2026-10-03 Lidar angle tweak
2026-10-04 Flipped camera
